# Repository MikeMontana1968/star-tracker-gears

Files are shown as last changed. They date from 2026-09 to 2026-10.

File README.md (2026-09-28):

# Sidereal star tracker

A standalone device that turns a camera at one revolution per **sidereal day**
(86164.0905 s) for wide-field astrophotography. It wakes at dusk, configures and
starts a GoPro HERO6 night lapse, tracks until dawn, stops the camera, and
rewinds ready for the next night.

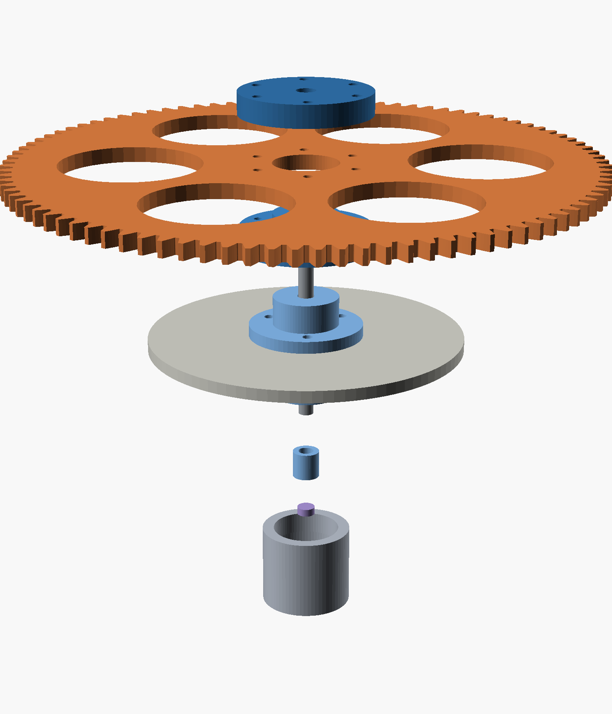
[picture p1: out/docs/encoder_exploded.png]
assembly


---

> **Picking this up again?** Read **[RESUME.md](RESUME.md)** first. The
> controller PCB (Rev C, for the 30-pin ESP32 in hand) is generated, clean
> in ERC and DRC, and ready to order.
>
> **Building it?** The illustrated assembly guide is
> [docs/assembly_guide/stjarnspar.html](docs/assembly_guide/stjarnspar.html):
> gearbox, board, smoke test, wiring, first power-up, use, and the schematics.
> Rebuild it with `python docs/assembly_guide/build.py` (needs Fritzing 1.0.8
> and KiCad 10). The Fritzing wiring project is
> [hardware/fritzing/star_tracker_wiring.fzz](hardware/fritzing/star_tracker_wiring.fzz),
> generated by `gen_fritzing.py` from the KiCad layout.

## Where this stands

| Area | State |
|---|---|
| Gearbox design | **Settled.** 2048:1, verified in CAD, every STL manifold |
| Printer calibration | **Measured.** Post/hole offset 0.50 mm; motor pinion bore pending one test print |
| Backlash | **Validated** on a test pair at 0.25 mm. One drag spot traced to the pinion — reprint with Z Seam = Random |
| Baseplate | **Ordered** from SendCutSend, 4.3 mm 6061 |
| Output shaft + encoder | **Designed**, needs the bearing gauge printed before the tower |
| Electronics | **PCB Rev C** ([hardware/PCB.md](hardware/PCB.md)) — 150 x 100 mm, all through-hole, every module socketed, generated from source; laid out for the 30-pin ESP32 after the pin check. ERC/DRC clean, not yet fabricated |
| Firmware | **Architecture settled** ([FIRMWARE.md](FIRMWARE.md)); nothing written beyond the timing core |
| Under the sky | Not yet |

**Next three things**, in order:

1. Print `_scratch/BEARINGGAUGE_pockets.stl`, set `$BrgFit`, then print the tower.
2. Print `pinion.stl` + the two bore variants next to `stage.stl`; keep the one
   that slides onto the NEMA17 shaft without force.
3. Build the polar wedge. **Before** the gearbox — see §2 below.

---

## The train

```
NEMA17 --15T--> [120T|15T] --> [120T|15T] --> [120T|24T] --> 96T --> camera
   module 1.0       8:1            8:1            8:1        4:1
                                                        module 2.0
```

**8 × 8 × 8 × 4 = 2048 : 1**

| | |
|---|---|
| microsteps / sidereal day | 13,107,200 (200 steps × 1/32 × 2048) |
| step interval | 6573.80 µs |
| step rate | 152.13 steps/s |
| motor speed | 1.426 rpm |
| output resolution | 0.099 arcsec/µstep |
| centre distances | 67.5 / 67.5 / 67.5 / 120.0 mm |
| gear stack | 226.5 × 279 mm envelope, 24.5 mm tall |
| baseplate | 121.5 × 174 × 4.3 mm, ~182 g |

---

## The two things that actually matter

Everything else in this project falls out of these.

### 1. Only the final pinion's radius sets short-exposure trailing

For any mesh, both gears contribute equally to output error per unit
eccentricity — the pinion's smaller radius exactly cancels its higher reduction.
But their *periods* differ, and trailing depends on how much the error moves
**during** an exposure:

```
excursion over exposure t  =  (e / r_pinion) × 2π t / 86164
```

Only `r_pinion` survives. That one equation drove the redesign from 4608:1 to
2048:1: a module-2 24-tooth final pinion (r = 24 mm) instead of module-1 15-tooth
(r = 7.5 mm) cuts a 0.1 mm eccentricity from ~60 arcsec to ~19 arcsec on every
300 s sub. Stages 1–3 divide by 2048, 256 and 32 — they can be as sloppy as the
printer likes.

### 2. Polar alignment dominates all of it

```
1° of misalignment  →  ~16 arcsec/min of drift
```

That swamps every mechanical error above. A sight tube down the RA axis getting
you to 0.25° is worth more than any amount of gear precision. **Build the wedge
first.**

Derivations, rejected alternatives and the design history are in
**[DESIGN_NOTES.md](DESIGN_NOTES.md)**.

---

## Layout

Square fold, 90° at each stage. Shaft centres in mm:

| Shaft | x | y | Carries |
|---|---|---|---|
| 0 motor | 0 | 0 | 15T module-1 pinion |
| 1 | 67.5 | 0 | 120T + 15T |
| 2 | 67.5 | 67.5 | 120T + 15T |
| 3 | 0 | 67.5 | 120T + **24T module-2** |
| 4 output | 0 | −52.5 | 96T module-2, 196 mm OD, on bearings |

**Constraints this layout imposes** — all three were found by drawing it to scale:

- **Nothing over Ø13 mm inline at shafts 0–3.** Tightest radial clearance is
  `67.5 − 61 − 2.5 = 4.0 mm`, shaft to neighbouring wheel tip. A 625ZZ (16 mm)
  gives −1.5 mm and collides; a Ø10 spacer leaves 1.5 mm. **Never fit a stock
  5 mm shaft collar at shafts 2 or 3.**
- **Shafts 0 and 1 must stay below 19 mm.** The output wheel sits over both. A
  stock NEMA17 shaft is 24 mm and fouls it — trim to ~10 mm above the plate.
- **No top plate on shafts 0 and 1**, same reason. Cantilever them; their errors
  divide by 2048 and 256, so it costs nothing.

**Every mesh needs its own Z band.** `pinion_tip + wheel_tip = a + 2m` always, so
a pinion collides with any adjacent wheel, mating or not. Four meshes, four
bands, irreducible. Band *height* can shrink (3 mm faces take the stack from
24.5 to 16 mm) but band *count* cannot.

---

## Baseplate

121.5 × 174 × **4.3 mm** 6061 aluminium, ~182 g (4.3 was the nearest stock to
the 4.0 designed). Cut, not printed — too big for the bed, and it wants
stiffness rather than strength.

Thickness is dimensionally free here: **all gear heights reference the plate's
top face**, so it lives below the datum. It only moves fastener lengths.

The outline is a hull of lobes at the five shaft centres, **not** a slab under
the whole gear footprint: the wheels overhang on purpose, so the plate only
carries the shafts and the motor. That is what takes it from ~740 g to 170 g.

The wedge/tripod interface is **4 × M5 on Ø50 centred on the output axis**, not
on the plate centroid. The camera moment gets reacted where it is generated, and
that short load path is why 4 mm is enough.

- `out/docs/baseplate_cut.dxf` — **send this**, 4 ARC + 4 LINE + 16 CIRCLE.
  State **mm** on upload; R12 DXF has no reliable units record
- `out/docs/baseplate_cut.svg` — same geometry as SVG, 17 closed contours
- `out/docs/baseplate_template.pdf` — 1:1 on US Letter, two scale bars
- `out/docs/baseplate_assembly_guide.pdf` — bench reference: component outlines,
  spacer heights, fastener sizes. **Not to scale**, by necessity — the gear
  footprint is 226 × 279 mm

`baseplate_geom.py` is the single source for all three, so they cannot drift.
Never export DXF from OpenSCAD — it emits 708 loose LINE segments and no
circles at all.

---

## Output shaft and AS5600 encoder

The output is the one shaft that rotates. The encoder magnet must sit on the axis
and turn with the wheel, and the camera load wants real bearings anyway.

Printed tower halves, hubs, washer, cap and bracket, plus a 5 mm ground shaft
**cut to 55 mm**, 2 × 625ZZ, a **diametric** 6 × 2.5 magnet and an AS5600
breakout. Verified: **magnet face to die = 2.0 mm**, inside the sensor's
0.5–3.0 mm window; bearing centres 30 mm apart.

Three design points worth not undoing:

- **The tower halves clamp the baseplate between them** (Rev B). Rev A's cone
  under the flange sat inside the plate. See PRINTING.md.

- **The wheel locates on a Ø22 register** on the lower hub and is clamped by six
  M3 — not centred by its own bore. A printed 5.2 bore on a 5 mm shaft is worth
  ~0.2 mm of eccentricity, which is exactly what §1 says to avoid.
- **The sensor bracket registers on the same tower boss that holds the lower
  bearing, and stops against the tower's clamp disc.** The AS5600 needs the
  magnet centred within ~0.25 mm and gapped at 2.0 mm; both come from printed
  features rather than from careful assembly.

Firmware aid: the AS5600's `AGC` and `MAGNITUDE` registers report "too far / too
close" as a number, so the air gap is measured, not guessed.

---

## Scheduled operation

Full architecture, cycle diagram, BOM and pin map: **[HARDWARE.md](HARDWARE.md)**.

- **ESP32, not a Pi.** Unattended robustness: a flat battery mid-write corrupts
  an SD card, LittleFS comes back. Also ~0.6 W cheaper, ≈7 Wh a night.
- **GoPro over WiFi, not BLE.** The documented GoPro BLE API starts at HERO9 —
  the earlier HERO5 Bluetooth failure was expected, not a Pi problem. HERO6 uses
  the `gpControl` HTTP API at 10.5.5.9, woken by a magic packet.
- **Captive web UI on the ESP32's own AP.** No app, no pairing. One radio means
  one mode at a time, which keeps the state machine simple.
- **~43 Wh per night, 69% of it the camera.** Three nights unaided needs 130 Wh;
  a 6 Ah pack plus a 20 W panel is lighter and never runs out.

**Two cycle rules that are not obvious:** always approach the start angle from
the forward direction (rewind reverses ~750 arcsec of backlash, which otherwise
gets taken up as drift during your first subs), and bias the counterweight so the
mesh stays loaded on one flank.

### Why there is no speed feedback loop

A stepper is synchronous, and the ESP32 crystal is ±20 ppm — over a 300 s exposure
that is 0.000025° at the output. There is nothing for a speed loop to correct. Use
StallGuard for *stall detection*, which is a real failure mode.

What must be exact is the step interval: 6573.80 µs is not an integer, and
rounding costs ~5 s/day of drift. `sidereal_drive.ino` carries the remainder in a
64-bit accumulator, so the rate is exact for **any** ratio — which is what freed
the design to choose gears for mechanical convenience.

---

## Printer calibration — measured, not guessed

These live at the top of `build.ps1`. They are the hardest-won numbers here.

| Constant | Value | How it was found |
|---|---|---|
| `$Bore` | 5.20 | gears run on 4.88 mm 20d nails |
| `$MotorBore` | 5.45 | NEMA17's ground 5.00 mm shaft needs a bigger bore than the nails |
| `$PostD` | 4.70 | fit gauge |
| `$BrgFit` | 0.50 | **provisional** — print the bearing gauge |

**A printed post must run ~0.50 mm under a printed hole's nominal diameter** for
a snug rotating fit on this printer. That is hole shrink plus post growth
combined, and it is on the high side of typical (0.30–0.40), which hints flow
runs a few percent hot.

Three gauges exist because these cannot be predicted, only measured:
`FITGAUGE` (posts), `BOREGAUGE` (holes), `BEARINGGAUGE` (625ZZ pockets).

---

## Repo layout

```
star_tracker_gears.scad     the model — single source for every part
make_baseplate_pdf.py       1:1 drilling template (reportlab)
build.ps1                   regenerates every artifact
firmware/sidereal_drive/    ESP32 sketch
PRINTING.md                 what to print, in what order, with what settings
DESIGN_NOTES.md             why the gearbox is what it is
HARDWARE.md                 electronics architecture, BOM
FIRMWARE.md                 firmware architecture, pin map, build order — START HERE for code
hardware/                   the controller PCB, generated from Python
  PCB.md                    board design notes, jumpers, assembly order
  design.py                 netlist + values + the ESP32/TMC pin maps
  place.py                  floorplan; layout.py packer; route.py maze router
  star_tracker_ctrl/        the generated KiCad project
out/                        generated — meshes gitignored
  docs/                     renders, laser SVG, baseplate SVG, template
  _scratch/                 calibration gauges, test jig, superseded exports
```

## Building

```powershell
.\build.ps1                     # everything
.\build.ps1 -Group gears        # the parts you print
.\build.ps1 -Group encoder      # output shaft assembly
.\build.ps1 -Group calibration  # the three gauges
.\build.ps1 -Group docs         # renders, SVGs, PDF
.\build.ps1 -List               # show targets without building
```

Needs OpenSCAD 2021.01+ and Python with `reportlab`. Every STL target is checked
for `Simple: yes` and the build fails if one is not.

---

## Traps worth remembering

Each of these cost real time and none of them announce themselves.

- **OpenSCAD: `children()` nested inside `union()` inside `difference()` inside
  `if()` does not resolve.** The section cut silently did nothing. Apply cuts at
  the call site instead.
- **OpenSCAD preview mis-renders `difference()` when children carry `color()`.**
  Geometry was correct all along; only the OpenCSG preview lied. Section images
  need `--render`, which then discards colour — hence the exploded view.
- **PowerShell 5.1 strips inner quotes** from native-exe arguments, so
  `part="spacers"` arrives as a bare variable. Backslash-escape them. And `2>&1`
  on a native command wraps stderr in ErrorRecords that abort under
  `$ErrorActionPreference = 'Stop'`.
- **A part can be un-printable in every orientation.** The bearing tower had a
  166 mm2 first layer one way up and an 8 mm 90° ledge the other. Splitting it
  fixed the printing. Check bed contact area, not just overhang angle.
- **Check a printable part against its neighbours, not just the bed.** Rev A's
  split added a cone for printability that sat inside the aluminium plate. It
  was found by drawing the assembly guide, not by the build. Rev B puts the
  plate between the halves, so each prints plate-face-down and only narrows
  going up.
- **Verify meshes, not file sizes.** Bounding-box checks caught a wheel that had
  changed only in float formatting, and a D-shaft cut that had sliced the pinion
  into five disconnected bodies (`Volumes: 5` instead of 2).
- **Binaries need `.gitattributes`.** Without it a fresh Windows clone rewrites
  LF to CRLF *inside* the PDF and PNGs and corrupts them.

## Order of work

1. Calibration gauges, then the test pair. Tune `backlash`.
2. **Build the polar wedge before the gearbox.**
3. Open-loop drive, 50 mm lens, one 5-minute sub. **Measure the trailing.**
4. Only then decide what to fix. Adding an encoder before you have data is
   solving an imaginary problem — the encoder in this design is for *scheduling*
   and stall detection, not for correcting tracking.

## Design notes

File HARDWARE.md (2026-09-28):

# Hardware — scheduled star tracker

Scope beyond the gearbox: a standalone device that wakes at dusk, configures and
starts a GoPro HERO6 night lapse, tracks at sidereal rate until dawn, stops the
camera, and rewinds ready for the next night.

---

## 1. Decisions, and why

### Controller: ESP32, not a Pi

| | ESP32 | Pi Zero W | Pi 4 |
|---|---|---|---|
| Idle power | ~0.3 W | ~0.9 W | ~3 W |
| Boot | instant | ~30 s | ~30 s |
| Survives a flat battery mid-write | yes | **SD corruption risk** | same risk |
| Step timing | hardware timers, no OS jitter | userspace, fine in practice | same |
| Web UI effort | moderate (ESPAsyncWebServer) | trivial (Flask) | trivial |
| RTC | needs DS3231 | needs DS3231 | needs DS3231 |

The deciding factor is not speed, it is **unattended robustness**. This device
sits outside for days and will eventually have its battery go flat mid-operation.
An ESP32 comes back up in a second with its LittleFS schedule intact; a Pi with a
half-written SD card may not come back at all. The extra 0.6 W also costs ~7 Wh a
night, which is real against a 43 Wh budget.

A Pi Zero 2 W with a **read-only root filesystem** is a legitimate alternative if
you would rather write Python — that closes the corruption gap. It does not close
the power or boot-time gap. A Pi 4 is the wrong shape for a battery device.

### Camera control: WiFi, not Bluetooth

Your earlier Pi-Zero/HERO5 Bluetooth failure was not a Pi problem — it was
expected. **The documented GoPro BLE API (OpenGoPro) starts at HERO9.** HERO5 and
HERO6 are controlled over WiFi through the `gpControl` HTTP API, which is well
documented by the community
([KonradIT/goprowifihack](https://github.com/KonradIT/goprowifihack/tree/master/HERO6)).

- Camera is the access point; controller joins it. Base URL `http://10.5.5.9/gp/gpControl`
- Wake from standby with a **Wake-on-LAN magic packet** to the camera's WiFi MAC,
  UDP port 9 (documented for HERO6)
- `GET /gp/gpControl/status` returns the full state as JSON
- `GET /gp/gpControl/setting/<id>/<value>` for exposure, interval, ISO limit
- `GET /gp/gpControl/command/shutter?p=1` / `p=0` start and stop
- `GET /gp/gpControl/command/system/sleep` standby

**Do not hardcode setting IDs from a blog post.** `GET /gp/gpControl` returns the
camera's own settings tree — dump it from your actual HERO6 and read the night
lapse mode and shutter IDs out of it. Firmware ships a `discover` command to do
exactly that.

**Caveat to verify on your camera:** `system/sleep` is standby, not off. The
camera keeps its WiFi radio listening so WoL can reach it, and that draws from
the internal battery. Budget for it, or cut the USB rail during the day and let
the internal battery hold standby — the load switch in the BOM lets firmware
choose. Measure it before trusting either.

### Phone interface: captive web UI, not an app

The ESP32 raises its own AP on a button press, serves a single page, and takes a
JSON schedule. No app to install, no pairing, works from any phone or laptop, and
sidesteps BLE entirely. **One radio means one mode at a time** — the controller
is either its own AP (configuring) or a station on the GoPro's AP (commanding the
camera). Never both. That constraint is what makes the state machine simple.

### Position: absolute encoder, so "home" needs no search

An **AS5600** on the output shaft reports absolute angle over I²C at power-up —
12-bit, 0.088° (5.3 arcmin). No homing sweep, no index hunt, and the same sensor
gives you skip detection during tracking.

This requires the output shaft to **rotate in bearings** rather than being a fixed
nail with the wheel turning on it, so the magnet can sit on the shaft end. That is
a change worth making regardless: the output carries the camera and deserves real
bearings.

Cheaper alternative: an opto-interrupter and a printed flag on the wheel rim,
~±0.06° repeatable, but it needs a homing sweep at power-up and gives no
continuous feedback. Listed as optional in the BOM.

---

## 2. Operating cycle

```
  IDLE (deep sleep, RTC alarm armed)
    |
    v  alarm at astronomical dusk - lead time
  ORIENT      read AS5600, slew to the start angle, approach FORWARD
    |
    v
  WAKE CAM    WoL magic packet, join GoPro AP, poll /status until ready
    |
    v
  CONFIGURE   set night lapse mode, shutter, ISO limit, interval
    |
    v
  RECORD      shutter?p=1, then DROP WIFI and start stepping
    |
    v  ...tracking at 6573.80 us/microstep...
    v  alarm at sunrise
  STOP CAM    rejoin AP, shutter?p=0, system/sleep, drop WiFi
    |
    v
  REWIND      slew back, overshoot, approach start FORWARD
    |
    v
  IDLE
```

Two rules that are not obvious:

**Always approach the start angle from the forward (tracking) direction.**
Backlash referred to the output is dominated by the final mesh:
`0.35 mm / 96 mm = 3.6 mrad ≈ 750 arcsec`. Rewinding reverses the gear train, so
if you stop on the reverse stroke that lost motion is taken up during your first
minutes of tracking — as drift. Overshoot and come forward.

**Keep the mesh loaded.** With a perfectly balanced camera the tracking torque
is near zero and the teeth can rattle across the backlash. Deliberately bias the
counterweight so the load always pulls the same way.

---

## 3. Power

Measured against a 12-hour night:

| Load | Power | Per night |
|---|---|---|
| GoPro HERO6, night lapse over USB-C | 2.5 W | 30.0 Wh |
| Stepper + TMC2209 tracking | 0.75 W | 9.0 Wh |
| ESP32 awake, radio off | 0.3 W | 3.6 Wh |
| RTC + encoder | 0.05 W | 0.6 Wh |
| GPS, powered only for the nightly fix | 0.22 W | **<0.1 Wh** |
| Rewind slew | 3 W for ~4 min | 0.2 Wh |
| **Total** | | **~43 Wh** |

**The camera is 69% of the budget.** Any power optimisation that is not about the
GoPro is noise.

Your 3-day schedule therefore needs ~130 Wh plus daytime standby. That is a
12 V 12 Ah LiFePO4 — about 1.8 kg. **A 12 V 6 Ah pack plus a 20 W solar panel is
lighter, cheaper, and makes the device indefinitely autonomous** — 43 Wh is about
four hours of decent sun. For a device whose entire job is to sit outside all day
doing nothing, solar is the obvious fit.

---

## 4. Bill of materials

Prices are rough and vary; treat as sizing, not quotes.

### Control board (see [hardware/PCB.md](hardware/PCB.md))

Everything in this table lives on the `star_tracker_ctrl` PCB. It is
**entirely through-hole**, and every module sits in a socket rather than being
soldered down.

| Qty | Ref | Item | ~USD | Notes |
|---|---|---|---|---|
| 1 | — | PCB, 127 x 76.2 mm, 2-layer, 1.6 mm | 12 | qty 5 from a cheap fab |
| 1 | — | ideaspark ESP32 + 0.96" OLED, 30-pin, CH340 | 10 | **have**; rows 27.94 mm, pin check done (no PSRAM, OLED on 21/22) |
| 2 | J20/J21 | 1x15 female header, 2.54 mm | 2 | the ESP32 socket |
| 1 | — | TMC2209 StepStick, UART mode | 7 | BTT / Fysetc / Watterott |
| 1 | J30/J31 | 1x08 female header, 2.54 mm | 1 | the driver socket |
| 1 | — | DS3231 RTC module (ZS-042) + CR2032 | 4 | ±2 ppm. **Not** DS1307 |
| 1 | J6 | 1x06 female header | 1 | RTC socket |
| 1 | — | AS5600 encoder module | 4 | remote, on the encoder bracket |
| 1 | — | Diametric magnet 6 x 2.5 mm | 2 | must be **diametric** |
| 1 | — | **GY-NEO6MV2 GPS module** (NEO-6M) + antenna | 8 | time, date and position. **PPS is not on its 4-pin header** — solder a lead at the PPS LED |

### Power stage (on the PCB)

12 V in, protected, to a 5 V 3 A switching rail with a firmware-switched
camera output.

| Qty | Ref | Item | ~USD | Notes |
|---|---|---|---|---|
| 1 | U2 | **LM2596T-5.0**, TO-220-5 | 2 | 150 kHz, 3 A, fixed 5 V |
| 1 | — | TO-220 clip-on heatsink | 1 | **fit it** — see PCB.md §5 |
| 1 | L1 | 33 µH radial power inductor, >=3 A | 2 | 12 mm body, 5 mm pitch |
| 1 | D3 | 1N5822, 3 A 40 V Schottky, DO-201AD | 0.5 | catch diode |
| 1 | C3 | 470 µF 25 V low-ESR | 1 | buck input |
| 1 | C5 | 220 µF 25 V low-ESR | 1 | buck output |
| 1 | C1 | 470 µF 25 V | 1 | 12 V bulk |
| 1 | C11 | 100 µF 25 V low-ESR | 1 | **VMOT, at the driver socket** |
| 2 | Q1 Q2 | IRF4905 P-MOSFET, TO-220 | 2 | reverse-polarity + camera switch |
| 1 | Q3 | 2N3904 NPN, TO-92 | 0.2 | gate driver for Q2 |
| 1 | Q4 | 2N3906 PNP, TO-92 | 0.2 | GPS 5 V high-side switch |
| 1 | Q5 | 2N3904 NPN, TO-92 | 0.2 | drives Q4 from GPIO 17 (GPS_EN) |
| 1 | D1 | 1N4744A 15 V zener, DO-41 | 0.2 | Q1 gate clamp |
| 1 | D2 | P6KE20CA TVS, DO-15 | 0.5 | input transient clamp; bidirectional |
| 1 | F1 | 5x20 mm fuse holder + 3 A fuse | 2 | PCB clips |
| 3 | LED1-3 | 3 mm LED (grn, grn, **red**) | 0.5 | 5 V / camera / status. LED3 runs off a 3.3 V GPIO, so red + 330 R — blue would barely light |
| 1 | SW1 | 6 mm tactile switch | 0.3 | config + wake |

### Connectors and passives (on the PCB)

| Qty | Ref | Item | ~USD | Notes |
|---|---|---|---|---|
| 2 | J1 J3 | 2-pos screw terminal, 5 mm | 1 | 12 V in, camera 5 V out |
| 1 | J4 | 4-pos screw terminal, 5 mm | 1 | motor |
| 1 | J2 | USB-A receptacle, THT horizontal | 1.5 | camera; D+/D- shorted |
| 1 | — | 1x40 male header strip, 2.54 mm | 1 | cut for J5/J7-J11/JP3-JP5 |
| 5 | — | 2.54 mm jumper shunts | 0.5 | MS1, MS2, PDN_ALT |
| 9 | C2.. | 100 nF ceramic, 2.5 mm pitch | 1 | decoupling |
| 2 | C7 C9 | 100 µF 16 V / 10 V | 1 | camera rail, 3V3 |
| 19 | R1.. | 1/4 W resistors, see PCB.md | 1.5 | 2x 1% for the battery divider |
| 4 | H1-H4 | M3 standoff + screw | 2 | |

### Motion

| Qty | Item | ~USD | Notes |
|---|---|---|---|
| 1 | NEMA 17 pancake, ~13 N·cm, 0.7 A | 14 | 250× torque margin; run at 300–400 mA |
| 2 | 625ZZ bearing 5 × 16 × 5 | 3 | output shaft only |
| 1 | 5 mm ground shaft | 4 | output shaft, cut to **55 mm**; carries the encoder magnet |
| 1 | 20d bright common nails, small box | 6 | 4.88 mm, shafts 1–4 |
| 1 | M3 hardware assortment | 8 | grub screws, caps, washers |

### Power

| Qty | Item | ~USD | Notes |
|---|---|---|---|
| 1 | 12 V 6 Ah LiFePO4 with BMS | 45 | ~1.8 nights unaided |
| 1 | 5 V 3 A buck converter | 6 | camera rail; **not** a linear regulator |
| 1 | 20 W solar panel + PWM/MPPT controller | 45 | *recommended* — makes it indefinite |
| 1 | Inline fuse holder + 3 A fuse | 3 | |
| 1 | XT60 or 5.5/2.1 mm barrel pair | 4 | |

### Camera

| Qty | Item | ~USD | Notes |
|---|---|---|---|
| 1 | GoPro HERO6 | — | have |
| 1 | Short right-angle USB-C cable | 8 | |
| 1 | 6-wire capsule slip ring | 12 | *optional* — a slack loop covers 180° |
| 1 | GoPro frame + ¼"-20 adapter | 8 | |
| 1 | Counterweight hardware | 6 | bias it to keep the mesh loaded |

### Enclosure

| Qty | Item | ~USD | Notes |
|---|---|---|---|
| 1 | IP54 project box | 15 | |
| 3 | Cable glands | 4 | |

The transistor switch on the GPS 5 V feed is there for a reason: left
powered the NEO-6M draws 30-45 mA around the clock, roughly 5 Wh a day doing
nothing at all. Switched on only for the nightly fix, it costs under 0.1 Wh.

**Roughly $205 without solar, $255 with** (the PCB and its discrete
power stage replace the perfboard, the buck module and the load-switch module).

---

## 5. Pin map

> **Superseded — see [FIRMWARE.md §4](FIRMWARE.md#4-pin-map--as-built).**
> The table below predates the OLED devkit and is missing the DS3231 interrupt
> line, without which the RTC alarm cannot wake the ESP32 from deep sleep.
> FIRMWARE.md §4 is the authoritative map. Kept here for the wiring rules only.

| ESP32 | To | Note |
|---|---|---|
| GPIO 25 | TMC2209 STEP | LEDC for slew, timer ISR for tracking |
| GPIO 26 | TMC2209 DIR | |
| GPIO 27 | TMC2209 EN | active low |
| GPIO 17 | TMC2209 PDN_UART | via 1 kΩ for single-wire |
| GPIO 16 | TMC2209 UART RX | |
| GPIO 21 / 22 | I²C SDA / SCL | DS3231 @0x68, AS5600 @0x36 — no conflict |
| GPIO 4 | config button | to GND, internal pull-up |
| GPIO 34 | battery sense | ADC via divider; input-only pin |
| GPIO 35 | opto home flag | *optional*; input-only pin |
| GPIO 32 | camera 5 V load switch | |
| GPIO 2 | status LED | onboard |

Avoid GPIO 6–11 (flash) and 0/12/15 (strapping).

**Wiring rules that kill drivers if ignored:** 100 µF low-ESR across VMOT right
at the TMC2209; common ground between ESP32 and driver; never unplug the motor
with power applied; TMC2209 VDD from **3.3 V**, not 5 V.

---

## 6. Open items

- [ ] Dump `/gp/gpControl` from the actual HERO6 and pin down night-lapse mode
      and shutter setting IDs
- [ ] Measure HERO6 standby draw with WiFi listening — decides whether the day
      rail stays on
- [ ] Confirm WoL wakes your camera reliably from cold-ish standby
- [ ] Redesign the output shaft: two 625ZZ bearings, rotating shaft, encoder
      magnet at the lower end, camera platform above
- [ ] Confirm the HERO6 keeps its AP rejoinable after the ESP32 disconnects
      mid-record — if not, the dawn stop has to become a load-switch cut, which
      loses the last file
- [ ] Cable routing for 180° of sweep — slack loop vs slip ring
- [ ] Decide battery vs battery+solar

Firmware architecture, state machine, schedule format and build order:
**[FIRMWARE.md](FIRMWARE.md)**.

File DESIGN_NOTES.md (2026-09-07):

# Star Tracker Gear Drive — Design Notes

Working notes for a printed gear train that rotates a camera at one revolution
per sidereal day, driven by a stepper on an ESP32.

`README.md` is the build sheet — what to print and what to set.
This file is the *reasoning*: why these numbers, and what was rejected.

Status: design settled at **2048:1** with a module-2 final stage. Accuracy
targets are deliberately loose; first light intended on a 50 mm lens.

The 4608:1 module-1 train described in §2 was the first design. It was replaced
after §3 showed the final *pinion* radius, not the wheel, sets short-exposure
trailing — see §3a. The history is kept because the reasoning still applies.

---

## 1. Tools surveyed

Before writing a custom generator, the existing options:

**Browser, no install**

| Tool | Notes |
|---|---|
| [STLGears](https://www.stlgears.com/generators/3dprint) | Fast one-offs. Spur/helical/bevel/rack, direct STL, no account. |
| [Gear Generator Pro](https://geargenerator.pro/) | Widest coverage — spur, helical, bevel, worm, rack, sprockets. Live 3D preview. |
| [EasyGear Maker](https://easygear.ddns.net/en/) | Best of the web tools if the mesh has to *work*: true involute, exposes profile shift and backlash, exports STEP. |
| [The Engineer Online](https://www.theengineer.online/) | DXF/SVG/STEP/STL including internal gears. Good when you want the 2D profile. |
| [geargenerator.com](https://geargenerator.com/) | Animates a train — useful as a ratio calculator, weak on export. |

**Parametric**

| Tool | Notes |
|---|---|
| [chrisspen/gears](https://github.com/chrisspen/gears) | OpenSCAD port of Dr. Kirsch's `getriebe.scad`. Spur/ring/bevel/worm/rack **plus prebuilt assemblies** with correct centre distances. The serious choice. |
| [playfultechnology/openscad-gears](https://github.com/playfultechnology/openscad-gears) | Lighter-weight alternative. |
| Fusion 360 Spur Gear add-in | Utilities → Add-Ins → Scripts. Gives real B-rep, so you can cut hubs and keyways into it. |
| FreeCAD FCGear workbench | Via Addon Manager. Full involute/bevel/worm/cycloid, parametric. |

**Why a custom file anyway:** this train needs *compound* gears (wheel + next
pinion on one hub) with mount features, printed 3× identically. Writing ~200
lines of self-contained OpenSCAD was less work than fighting a library's
assembly conventions, and it version-controls as text.

---

## 2. Ratio selection

Sidereal day = **86164.0905 s**.

Working backward from motor speed:

| Motor speed | Reduction needed |
|---|---|
| 1 RPM | 1436 : 1 |
| 3 RPM | 4308 : 1 |
| 10 RPM | 14361 : 1 |

Below ~1 RPM the motor's own 50-cycle/rev torque ripple starts to show.
Above ~5 RPM you buy extra gear stages you don't need. **~3 RPM is the sweet spot.**

Chose **4608 : 1 = 8 × 8 × 8 × 9** because it factors into one repeated part:

```
NEMA17 --15T--> [120T|15T] --> [120T|15T] --> [120T|15T] --> 135T --> camera
         8:1          8:1            8:1            9:1
```

Five printed parts, two distinct designs. At 200 steps/rev, 1/16 microstepping:

| | |
|---|---|
| microsteps / sidereal day | 14,745,600 |
| step interval | 5843.377 µs |
| step rate | 171.13 steps/s |
| motor speed | 3.209 RPM |
| output resolution | 0.088 arcsec/µstep |

Module 1.0, 20° PA. Centre distances **67.5 / 67.5 / 67.5 / 75.0 mm**.
ODs: 15T = 17 mm, 120T = 122 mm, 135T = 137 mm. All fit an Ender 3 bed.

**Don't chase "nice" numbers.** The software accumulator (§4) makes any ratio
exact, so gears get chosen for mechanical convenience, not numerology.

### Rejected: single-stage worm

60:1 or 90:1 in one stage is tempting, but it puts the motor at ~0.04 RPM —
deep into torque-ripple territory. Worms belong in the *final* stage, not as
the whole reduction. See §6.

---

## 3a. The correction that reshaped the design

The table in §3 tracks the **wheels**. It misses the pinions, and the pinions
are what matter.

For any mesh both gears contribute equally to output error per unit
eccentricity — the pinion's smaller radius exactly cancels its higher
reduction. But the periods differ, and trailing depends on how far the error
moves *during* an exposure:

```
excursion over exposure t  =  (e / r_pinion) x 2*pi*t / 86164
```

Only the final pinion's pitch radius appears. With the original 15T module-1
pinion (r = 7.5 mm) a 0.1 mm eccentricity gives ~60 arcsec over a 300 s sub —
nine times worse than the 135T wheel the §3 table fingered.

**Final design: 24T pinion / 96T wheel at module 2.0, 4:1.** r_pinion goes
7.5 -> 24 mm, and that 60 arcsec becomes ~19. Total ratio 8x8x8x4 = **2048:1**,
`USTEPS_PER_REV = 13,107,200` at 1/32 microstepping.

The same change makes the wheel laser-cuttable if you ever want it in metal:
module-1 tooth tips are 0.69 mm, module-2 tips are 1.43 mm.

A single defective tooth is a smaller problem than it first appears. Trailing
comes from error *changing* during an exposure, so a sub taken wholly inside one
tooth's engagement sees a constant offset that stacking removes. Only subs
straddling the bad tooth's entry or exit are damaged — about 6% of them.

## 3. Error budget — the useful part

Each shaft's eccentricity is divided by the reduction **downstream** of it:

| Shaft | rev/day | period | 0.1 mm eccentricity → output error |
|---|---|---|---|
| 0 (motor pinion) | 4608 | 18.7 s | ~0.001″ |
| 1 | 576 | 2.5 min | ~0.6″ |
| 2 | 72 | 20 min | ~4.6″ |
| 3 | 9 | 2.7 h | ~37″ |
| 4 (output, 135T) | 1 | 23.9 h | ~305″ |

**Only the last stage matters.** Stages 1–3 can be as sloppy as the printer
likes. This is why the output wheel is the biggest one — angular error scales
as 1/R, so print it as large as the bed allows.

The 305″ on the output sounds fatal but its *period* is a whole day, so within
a 300 s exposure you only see about **6.7 arcsec** of it:

```
excursion ≈ A × 2π × t_exposure / 86164
          = 305 × 2π × 300 / 86164 ≈ 6.7″
```

- 50 mm lens on APS-C ≈ 16 arcsec/px → invisible.
- 200 mm lens ≈ 4 arcsec/px → ~1.7 px of trailing, borderline.

**Start on a 50 mm.**

### What actually ruins subs

**Polar alignment.** Misalignment θ drifts at θ·ω where ω = 7.292e-5 rad/s:

```
1° = 3600″ → 3600 × 7.292e-5 = 0.263 ″/s = ~16 arcsec/min
```

That swamps every mechanical error above. Getting to 0.25° with a sight tube
down the RA axis buys more than any amount of gear precision. **Do this first.**

---

## 4. Why there is no speed feedback loop

A stepper is *synchronous* — it advances exactly one microstep per pulse. The
ESP32 crystal (±20 ppm) is the timebase, and over a 300 s exposure that is
±6 ms ≈ 0.000025° at the output. Four orders of magnitude better than the
mechanics. **There is nothing for a speed loop to correct.**

What feedback *is* worth having: **stall / skip detection.** A TMC2209 gives it
free over UART via StallGuard. An AS5600 on an intermediate shaft also works
(12-bit = 0.088°, ÷9 through the final stage = ~35″ at the output — coarse for
correction, fine for "is it still turning?").

### The one thing that must be exact

The step interval 5843.377… µs is **not** an integer. Rounding to 5843 µs loses
0.377 µs × 171 steps/s = 65 µs/s = **5.6 s/day ≈ 23 arcsec of drift.** Visible.

So never round — carry the remainder, Bresenham style:

```c
const uint64_t SIDEREAL_US    = 86164090500ULL;      // µs
const uint64_t USTEPS_PER_REV = 200*16*4608;         // 14,745,600

acc += SIDEREAL_US;
uint64_t dt = acc / USTEPS_PER_REV;   // alternates 5843 / 5844
acc -= dt * USTEPS_PER_REV;           // remainder carries forward
next_us += dt;
```

Long-term rate is exact for **any** gear ratio. Change `USTEPS_PER_REV` and
nothing else. Use `esp_timer_get_time()` (int64 µs, monotonic, never wraps),
not `micros()`.

Run the motor at **low current (300–400 mA)** — it needs almost no torque
through 4608:1, and low current means less vibration and heat.

---

## 5. The generator

`star_tracker_gears.scad`, self-contained, no libraries.

**Involute construction.** Flank angle at radius R:

```
θ(R) = ψ_pitch + inv(α) − inv(acos(r_base/R))
```

with `inv(a) = tan(a) − a`, and `ψ_pitch = 90/z` degrees minus the backlash
allowance. Below the base circle the flank extends radially (conservative —
a real trochoid root is more generous). Root fillets come from a morphological
closing, `offset(r=-f) offset(r=+f)`, which rounds concave corners only.

**Helix done right.** Twist is computed *per gear* from a shared helix angle β:

```
twist_deg = h · tan(β) / r_pitch · 180/π
```

Applying the same twist *degrees* to a 15T and a 120T — which most generators
do — produces gears that will not mesh, because `r` differs. Cutting in the
transverse plane also keeps centre distance exactly `m(z₁+z₂)/2`.

**Mount features** (§ README) — `mount_type` / `out_mount`:
`round`, `dshaft`, `hex`, `bearing`, `thread`. Plus an M3 grub screw and a
parametric bolt circle. Lightening holes compute their inner radius from
whatever the bolt circle and bearing boss need.

### Two constraints found the hard way

1. **A bearing pocket does not fit the compound `stage` gear.** A 625ZZ is
   16 mm across; the 15T pinion's root circle is 12.5 mm. The pocket eats the
   pinion. Bearings go in the **frame**, plain shaft through the gear — which
   is what a real gearbox does. Hence `mount_type` and `out_mount` are separate.

2. **A D-hole is the circle *minus* the flat side**, not the circle plus a slot.
   The first attempt cut an oversized slot outward, sliced teeth off, and
   produced 5 disconnected bodies. Caught by checking `Volumes:` in the render
   output — `2` means one solid, anything more means the part fell apart.

### Verification

All parts render manifold (`Simple: yes`, `Volumes: 2`) in every `mount_type`.
Console echo confirms `ratio = 4608 : 1` and
`centre distances = [67.5, 67.5, 67.5, 75]`.

```powershell
& "C:\Program Files\OpenSCAD\openscad.exe" -o out\stage.stl -D 'part="stage"' star_tracker_gears.scad
```

**Using the GUI:** F5 = fast preview, F6 = full render (needed before STL
export), F7 = export. `$t` is 0 under F5, so nothing moves — for motion use
**View → Animate**, then FPS 10 / Steps 100. Scrubbing the `Time` field by hand
is usually more informative than watching it spin.

The 135T wheel takes ~2 min to F6. That is `offset()` doing fillets on 135
teeth, not a hang. Set `fillet = 0` and `flank_pts = 8` while experimenting.

---

## 6. Upgrade path — same firmware

Replace stages 3 and 4 with a worm:

```
NEMA17 --15T--> [120T|15T] --> [120T|15T] --> 1-start worm --> 72T wheel
         8:1          8:1                            72:1
```

8 × 8 × 72 = 4608 : 1, so `USTEPS_PER_REV` changes to 200 × 32 × 4608.
A worm final stage has no backlash reversal, is nearly self-locking, and a
*bought brass* worm wheel removes the single largest error source in the design
(§3). This is what a real EQ mount does.

---

## 7. The lazier alternative

A **barn-door tracker** — hinged plate pushed by a threaded rod on a long lever
— gets ~1000:1 mechanical advantage for free, makes printed-part precision
almost irrelevant, and is a weekend build. It only tracks for about an hour
before tangent error accumulates, and needs an isosceles or curved-rod
correction beyond that.

If "get a feel" is genuinely the goal, that is the better *first* project.
The gearbox is the better second one.

---

## 8. Order of work

1. Print `test_pair`. Tune `backlash` until it turns freely with barely
   perceptible slop. Everything downstream depends on this one number.
2. Build the polar alignment **before** the gearbox.
3. Open-loop drive, 50 mm lens, one 5-minute sub. **Measure the trailing.**
4. Only then decide what to fix. Adding an encoder before you have data is
   solving an imaginary problem.

## Print settings (Ender 3 / V3 SE)

- Module 1.0 at 0.4 mm nozzle → ~1.57 mm tooth thickness at the pitch line,
  about 4 extrusion widths. Fine at these loads. **Do not go below module 1.0.**
- `backlash = 0.25` mm total per mesh is the PLA starting point. Binds → 0.35.
  Rattles → 0.15.
- 0.12–0.16 mm layers, **4 perimeters**, ≥40% infill. Perimeters carry the
  teeth, so more perimeters beats more infill.
- Flat on the bed, no supports. Lightening holes are already in the wheels.
- **PLA, not PETG** — PETG creeps under sustained load.
- Shafts: 5 mm. M5 bolts work. 625ZZ (5×16×5) on the last two shafts, which
  are the ones that matter.

---

## 9. Assembly constraints found during layout

Three of these only surfaced when the layout was drawn to scale. All are now
enforced in `star_tracker_gears.scad` or documented on the drilling template.

**Every mesh needs its own Z band — the stack cannot be flattened.** For any
mesh, `pinion_tip + wheel_tip = a + 2m`: the tip circles always overlap by two
modules. So a pinion collides with *any* wheel on an adjacent shaft, mating or
not. Four meshes, four bands, irreducible. What can shrink is band height —
3 mm faces and a 1 mm gap take the stack from 24.5 mm to 16 mm.

**The assembly is a pancake, not a staircase.** Drawn folded and at true scale
it is 226 mm across and 24.5 mm tall. The three 122 mm wheels overlap almost
completely in plan; only the Z staircase separates them.

**Spacer OD is the tightest fit in the box.** A spacer on shaft 2 shares a Z
band with shaft 1's wheel: `67.5 - 61 - 5.0 = 1.5 mm` at Ø10, and zero at Ø13.
Never fit a stock 5 mm shaft collar (12-16 mm OD) at shafts 2 or 3.

**The output wheel sits over shafts 0 and 1.** They must stay below 19 mm, and
cannot reach a top plate. Harmless — their errors divide by 2048 and 256.

**Consecutive wheels were originally coplanar** with zero axial gap, and the
lowest gear sat flat on the baseplate. Both fixed with `z_gap` and `sp_clr`.
`fw_pinion` is 2 mm wider than `fw_wheel` precisely so the axial gap can exist
while the pinion still covers the full wheel face.

## 10. Printer calibration

Measured, not assumed: **a printed post must run ~0.50 mm under a printed
hole's nominal diameter** for a snug rotating fit on this machine — hole shrink
plus post growth combined. High side of typical (0.30-0.40), which hints flow
runs a few percent hot.

Consequences: gears carry a 5.2 bore and run on **20d common nails (4.88 mm)**,
which fit the as-printed hole better than true 5.00 mm ground stock would. The
motor pinion is the exception — it goes on the NEMA17's ground 5.00 mm shaft
and needs ~5.45, with the D-flat scaled to match at `2.0 + (bore - 5.0)/2`.

These constants live at the top of `build.ps1`.

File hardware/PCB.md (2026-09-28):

# star_tracker_ctrl — controller PCB, Rev C

A 150 × 100 mm (5.9 × 3.9 in) two-layer carrier board for the sidereal
tracker: 12 V in, protected and fused, a 5 V 3 A switching rail, a
firmware-switched camera output, and sockets for the ESP32, the TMC2209 and
the DS3231.

Architecture, state machine and pin map: **[../FIRMWARE.md](../FIRMWARE.md)**.
Project-level BOM: **[../HARDWARE.md §4](../HARDWARE.md)**.

---

## 0. Read this before you order

Rev C is drawn for the module in hand, the **30-pin ideaspark ESP32 + 0.96"
OLED** (silkscreen `ESP32 OLED-0.96 V3.0`, DOIT DevKit V1 layout). These were
measured or checked on that module:

- [x] **Row spacing 27.94 mm (1.1 in), pitch 2.54 mm, 15 pins per side** —
      measured. [`design.py`](design.py) `ESP32_ROW_SPACING` / `ESP32_PINS_PER_SIDE`.
- [x] **Pin order** read off the module's silkscreen; the map is FIRMWARE.md §4.
- [x] **Pin check, 2026-09-27:** the OLED answers at `0x3C` on GPIO 21/22 (it
      shares the sensor bus, GPIO 4 stays free for WAKE), and there is **no
      PSRAM** — WROOM-class, GPIO 16/17 free.
- [ ] Using a different ESP32 board? Redo all three: measure the rows, read
      the pin order, run `firmware/pincheck`. A Heltec-style board with the
      OLED on GPIO 4/15 needs a different map.
- [ ] Check the DS3231 module's pin order is `32K SQW SCL SDA VCC GND`
      (ZS-042). Other orders exist; the socket is labelled.
- [ ] Look at your GPS module for a **PPS pad**. The common GY-NEO6MV2 brings
      out only `VCC RX TX GND` and drives an on-board PPS LED instead, so
      you will be soldering a flying lead. See §6.

Everything is through-hole, and every module is socketed. There are no SMD
parts and no DIP ICs — the only IC is the LM2596 in a TO-220.

---

## 1. What is on it

| Block | Parts | Notes |
|---|---|---|
| Input protection | F1, Q1, D1, D2, C1 | 3 A fuse, P-FET reverse polarity, TVS |
| 5 V 3 A buck | U2, L1, D3, C3, C5 | LM2596T-5.0, 150 kHz |
| Camera switch | Q2, Q3, R3–R5, J2, J3 | high-side P-FET, USB-A + screw terminal |
| ESP32 socket | J20, J21 | 2 × 1×15, 27.94 mm apart (30-pin module) |
| TMC2209 socket | J30, J31 | 2 × 1×8, 15.24 mm apart (StepStick standard) |
| Motor | J4 | 4-pos screw terminal |
| RTC | J6 | DS3231 module socket |
| Sensors | J7, J8, J10 | AS5600 (remote), opto home, I²C expansion |
| GPS | J9, Q4, Q5 | GY-NEO6MV2 on a switched 5 V feed, plus PPS |
| v2 | J11 | spare IO: GPIO 39, 35 (input-only) |
| Jumpers | JP3, JP4, JP5, J5 | PDN alt, MS1, MS2, DIAG |

---

## 2. Power input

```
  J1 +12V ── F1 3A ──┬── Q1 IRF4905 ──┬── +12V rail
                     │   (D→in, S→out)│
                    GND        R1 10k ┴ GND,  D1 15V zener G–S clamp
                                      │
                               D2 P6KE20CA ── GND
                               C1 470µF ──── GND
```

**Q1's orientation is the part people get wrong.** For reverse-polarity
protection with a P-channel MOSFET, the **drain** goes to the supply and the
**source** to the load — not the other way round. The body diode runs
drain→source, so wired this way it is forward-biased in normal use (the
channel carries the current anyway, at ~20 mΩ) and **reverse-biased when the
supply is backwards**, which is the whole point. Wire it source-to-supply and
the body diode happily passes −12 V straight into the board.

D1 clamps V<sub>GS</sub> if a transient gets past the TVS. D2 is
**bidirectional** (P6KE20CA, not the unidirectional …A) so there is no
polarity to get wrong at assembly.

## 3. 5 V 3 A buck — LM2596T-5.0

Pin order confirmed against TI SNVS124G Table 6-1:
**1 = V<sub>IN</sub>, 2 = Output, 3 = GND, 4 = Feedback, 5 = ON/OFF.**

| | |
|---|---|
| Topology | fixed 5 V, 150 kHz, 3 A |
| Input cap | C3 470 µF 25 V **low-ESR** |
| Inductor | L1 33 µH, ≥3 A, 12 mm radial |
| Catch diode | D3 1N5822, 3 A 40 V Schottky, cathode on the SW node |
| Output cap | C5 220 µF 25 V **low-ESR** |
| ON/OFF | tied to GND = always on (open is also on) |
| Feedback | straight to the +5 V rail — this is the fixed-output part |

**Low-ESR is not optional** on C3 and C5. A general-purpose electrolytic will
work at room temperature and then make the loop unstable on a cold night.

### Fit the heatsink

At 3 A out the LM2596 dissipates about 1.7 W. A bare vertical TO-220 is
roughly 60 °C/W to still air, so that is a 100 °C rise — too hot. The real
load is much lower (the camera is ~0.5 A, ~1.5 A while it charges its own
battery, plus ~0.15 A for the ESP32), which is 0.4–0.6 W and fine bare. **Fit
a clip-on heatsink anyway** — it costs a dollar and the failure mode is a
thermal shutdown at 2 a.m.

If you would rather have 94 % and no inductor, a Traco **TSR 3-2450** (SIP-3,
3 A, 6.5–36 V in) is a drop-in *concept* replacement, but it needs a footprint
this project does not ship — its pin pitch is not verified here. The Recom
R-78B5.0-2.0 has a stock KiCad footprint but is only 2 A, which is under spec.

## 4. Camera 5 V switch

```
  +5V ──┬── R3 10k ──┬── Q2 gate       GPIO32 ── R4 10k ── Q3 base
        │            │                                  R5 100k ── GND
        └── Q2 source│
                     └── Q3 collector ── (Q3 emitter → GND)
  Q2 drain ── +5V_CAM ── C7 100µF ── J2 USB-A / J3 screw terminal
```

GPIO high → Q3 on → gate pulled to ground → V<sub>GS</sub> = −5 V → Q2 on.
R3 holds the gate at the source so the camera is **off by default**, including
while the ESP32 is unpowered or its GPIO is floating; R5 does the same for the
base. IRF4905 at V<sub>GS</sub> = −5 V is roughly 30 mΩ, so ~0.1 V and 0.15 W
at 1.5 A.

J2's D+ and D− are shorted together — the "dedicated charging port"
convention, which is what tells a GoPro it may draw full current.

## 5. GPS

```
       GPIO17 ──R18 10k──┬── Q5 base          +5V ──┬── R16 10k ──┬── Q4 base
                     R19 100k                       │             │
                         │                          └── Q4 emitter│
                        GND     Q5 collector ──R17 1k─────────────┘
                                Q5 emitter ── GND
                                Q4 collector ── GPS_VCC ── C17 ── J9.2
```

GPIO high turns Q5 on, which pulls Q4's base down through R17 and switches
5 V onto the module. R16 holds Q4 off by default and R19 does the same for
Q5, so **the GPS is off while GPIO 17 floats at boot**. Q4 is a 2N3906: at
45 mA it drops about 0.2 V, and the module's own LDO makes 3.3 V from what
is left. Its TX output is 3.3 V logic, safe straight into the ESP32.

**Why switch it at all:** the 3.3 V and 5 V rails both stay up through deep
sleep, so an unswitched GPS would pull 30–45 mA around the clock — roughly
5 Wh a day, for a part that has a job for about ninety seconds each evening.

### J9 pinout

| Pin | Signal | Note |
|---|---|---|
| 1 | **PPS** | flying lead — see below |
| 2 | VCC | switched 5 V |
| 3 | RXD | net `ESP_TX_GPS_RX`: module RX ← ESP32 TX (GPIO 5) |
| 4 | TXD | net `GPS_TX_ESP_RX`: module TX → ESP32 RX (GPIO 18) |
| 5 | GND | |

Pins 2–5 are deliberately in the module's own `VCC RX TX GND` order, so its
4-wire cable plugs straight in. **Pin 1 is separate because the GY-NEO6MV2
does not break PPS out** — the NEO-6M's TIMEPULSE drives the on-board PPS LED,
so tap it there. Check your board first; some revisions do have a PPS pad.

PPS is worth wiring, but keep its value in proportion: it sets the RTC to
sub-second accuracy and *measures* your crystal's real ppm error. It does not
meaningfully improve tracking — 20 ppm over a 12 h night is 3.6 arcsec at the
output, and polar alignment beats that by a thousand.

## 6. Module orientation — read this before fitting anything

**Every module on this board sits in a socket.** The ESP32 (J20/J21), the
TMC2209 (J30/J31) and the DS3231 (J6) are all female headers — nothing is
soldered down, and any of them can be pulled and replaced.

That makes orientation the thing that bites, because a socket will happily
accept a module fitted the wrong way round.

### The rule

The ESP32 module viewed from the top with its USB at the bottom has the left
column (`EN … VIN`) down the left edge and the right column (`IO23 … 3V3`)
down the right. Laid on its side there are exactly **two** legal placements:

| Rotation | Left column | Pin 1 | USB |
|---|---|---|---|
| 90° CW | **TOP row** | RIGHT | LEFT |
| 90° CCW | BOTTOM row | LEFT | RIGHT |

**Anything else is a reflection and cannot be built.** Revision A of this board
had the left column on top with pin 1 at the *left*, which is neither — the
transform from module coordinates to board coordinates had determinant −1. The
module would have had to be flipped over to fit, and every single pin was on
the wrong signal.

This board uses the first form: both sockets at rotation 270, pin 1 (`EN`
on the upper row, `IO23` on the lower) at the right-hand end, **USB pointing
left**.

### What is printed on the board

- a dashed **body outline** for the ESP32 and the TMC2209, so you can see the
  module's extent and which way it lies before fitting it
- a large **`USB <<<`** at the left-hand end of the ESP32 outline
- a bold **`1`** beside pin 1 of all four sockets
- the **signal name beside every pin** of both modules
- the orientation stated in words inside the outline, where it is covered once
  the module is in and visible exactly when you need it

If your module's pin 1 does not land next to the `1`, stop — do not force it.

## 7. Grounding and the two routing constraints

GND is a **pour on both layers**, so return paths are short and the sensitive
things (AS5600 I²C, the step pulse) sit over solid copper.

Two constraints the layout is built around, both worth knowing before you move
anything:

**Through-hole pin rows cannot be crossed.** At 2.54 mm pitch with ~1.7 mm
pads the gap between adjacent pads is 0.84 mm, and a 0.3 mm track with 0.3 mm
clearance needs 0.9 mm. Worse, a through-hole pad blocks *both* layers, so
there is no "go under it on the back" escape. The ESP32's two header rows are
therefore walls across the middle of the board.

**So the GPIO map is chosen to suit the geometry.** Everything whose
destination is the bottom connector strip lives on the ESP32's **lower** row;
everything serving the driver, the camera and the power input lives on the
**upper** row. That is why WAKE is on GPIO 4 rather than 33, and PPS on
GPIO 23 rather than 36 — see the revision note in FIRMWARE.md §4. Corridors at
x ≈ 35–42 mm and x ≈ 91–99 mm carry what is left, mostly the power rails, and
a horizontal channel below the lower row fans the bottom-strip signals out.

This is also why the board grew from the 127 × 76.2 mm that "3 × 5 inches"
would give, first to 127 × 84 and then to **150 × 100**. Each time the limit
was the same: nets with nowhere to fan out between the lower header row and
the bottom connector strip, and corridors too narrow at the module's ends.
The current size gives ~12 mm corridors and a 32 mm deep fan-out channel,
which is what finally made routing comfortable rather than marginal.

## 8. Jumpers

| Ref | Default | What it does |
|---|---|---|
| JP4 | **GND** | MS1 — TMC2209 UART address bit 0 |
| JP5 | **GND** | MS2 — UART address bit 1 |
| JP3 | open | bridges PDN_UART to the alternate StepStick pin, if your module puts UART on position 5 instead of 4 |
| J5 | wire | DIAG — no vendor brings StallGuard out on the 16-pin header, so run a flying lead from the module's DIAG pad to this header |

Both address jumpers to GND gives UART address 0, which is what the firmware
assumes. **The TMC2209's V<sub>REF</sub> pot is unused** — run current is set
over UART with IRUN/IHOLD.

## 9. Building it

```powershell
cd hardware
python gen_board.py                       # schematic + board + BOM
& 'C:\Program Files\KiCad\10.0\bin\python.exe' fill_zones.py
```

The KiCad project is **generated, not hand-drawn**. Edit the source, not the
`.kicad_pcb`:

| File | Holds |
|---|---|
| `design.py` | the netlist, every value, the ESP32/TMC pin maps |
| `place.py` | the floorplan: fixed positions and packing regions |
| `layout.py` | courtyard extents, the region packer, the collision check |
| `route.py` | the two-layer maze router |
| `gen_board.py` | emits `.kicad_sch`, `.kicad_pcb`, `.kicad_pro`, `BOM.csv` |
| `kicadlib.py` | S-expression reader/writer and library loader |

Regenerating overwrites the project, so any edit you make in KiCad's GUI is
lost on the next run. For one-off tweaks that is fine — open the project and
edit. For anything you want to keep, change `design.py` or `place.py`.

Checks that run every time:

- `layout.check()` fails the build on any courtyard overlap or off-board part
- `kicad-cli sch erc` — currently clean
- `kicad-cli pcb drc` — see §8

## 10. Known state

**Rev C**, generated 2026-09-27 for the 30-pin ideaspark module, fully routed,
and checked with KiCad 10's own tools:

| Check | Result |
|---|---|
| ERC | **0 violations** |
| DRC — unconnected | **0** |
| DRC — clearance / shorts / hole-to-hole | **0** |
| DRC — silkscreen overlap | 68 + 6 over-copper, cosmetic |
| Parts | 71 placed + 4 mounting holes |
| Nets | 45 |
| Routing | 234 track runs, 82 vias, GND poured both sides; complete on pass 12 of 30 |

The silkscreen warnings are reference designators colliding with each other
and with the module pin legends on a dense board. Nothing about fabrication
or assembly depends on them.

**The router is a greedy maze router with randomised restarts**, not a
commercial autorouter. With a fixed seed, `gen_board.py` reproduces the same
board every time. If you change the floorplan and a net comes out unrouted,
the message names it — raise `passes` in `route.py`, or open the board and
route that one by hand.

**Always run the DRC after regenerating**, and read the unconnected items: a
GND pad the pour cannot reach passes the router and ERC and only shows there.

### Getting the ground pour to reach every pad

Worth knowing if you move things. A pad can be fenced in by signal tracks on
both layers — and through-hole pads block both — leaving the pour unable to
reach it. What fixed that here, in order of how much it mattered:

1. **Tight thermals.** `thermal_gap` 0.3 mm and `thermal_bridge_width` 0.4 mm,
   with `min_resolved_spokes` set to 1. Going from the 0.5 mm defaults took
   isolated pads from 8 to 1. Thermal relief is kept rather than using a solid
   pour connection, because soldering a through-hole ground pin into solid
   1 oz copper is genuinely unpleasant.
2. **`GND_RESCUE` in `design.py`**: pads the router connects to their nearest
   GND pad *before* any signal is routed. Rev C names the four GND end pins of
   the bottom connector strip (J6.6, J7.5, J8.1, J8.4) — the lower-row signals
   fan out between them and fenced a different two in on every attempt until
   all four were reserved. The list comes from the DRC, which knows the pour;
   the router does not (reserving every pad the router *itself* could not
   stitch, eleven of them, left six signals unroutable).
3. **An explicit GND stitch**, routed last at signal width, twice, so a
   straggler can connect to track laid after its own first attempt.
4. **Ground on end pins.** Interior pins on a 2.54 mm connector are
   unreachable by the pour — the gap between adjacent pads is 0.84 mm and the
   pour needs about 1.25 mm — so ground belongs on an end pin.

### Drill spacing

The router keeps every via centre clear of every pad and via hole by the
fab's 0.25 mm hole-to-hole minimum, whatever the nets. Its copper checks alone
let a GND via land 0.19 mm from a GND pad's hole, which is legal copper and an
illegal drill.
## 11. Fabrication

2 layers, 1.6 mm, 1 oz copper, HASL — no controlled impedance, no fine pitch,
no blind vias. Minimum track 0.4 mm signal / 1.0 mm power, minimum clearance
0.3 mm, smallest drill 0.4 mm (vias). Any cheap fab will build this at their
default rules.

```powershell
$cli = 'C:\Program Files\KiCad\10.0\bin\kicad-cli.exe'
& $cli pcb export gerbers --output gerbers star_tracker_ctrl\star_tracker_ctrl.kicad_pcb
& $cli pcb export drill   --output gerbers star_tracker_ctrl\star_tracker_ctrl.kicad_pcb
```

## 12. Assembly order

Lowest parts first, and test each rail before fitting the next stage.

1. Resistors, diodes, small ceramics.
2. Q1, D2, F1, C1 — then **apply 12 V and check the rail at Q1's source**,
   and check that reversing the supply gives 0 V and nothing gets warm.
3. U2 (with its heatsink), L1, D3, C3, C5 — **check 5 V** before going on.
4. Q2, Q3, C7, the USB socket — pull GPIO 32's pad high by hand and confirm
   the camera rail switches.
5. Q4, Q5 and their four resistors — drive the socket's GPS_EN pin (GPIO 17) high by hand and
   confirm ~4.8 V appears on J9 pin 2, and 0 V when it is low.
6. Electrolytics, LEDs, connectors, sockets last.
7. **Fit the modules only after all rails read correctly.**

The 5 V rail feeds the ESP32's on-board regulator through the module's `5V`
pin, and everything at 3.3 V comes back out of the module's `3V3` pin. Added
3.3 V load is only ~20 mA (AS5600, DS3231, TMC2209 V<sub>IO</sub>, pull-ups),
which the module's AMS1117 handles without complaint.

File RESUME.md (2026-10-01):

# RESUME — where this stands and what is next

Last touched 2026-10-01.

> **PCB FROZEN — Rev C Gerbers were sent to the fab house (2026-10-01).**
> Do NOT modify `hardware/star_tracker_ctrl/`, `design.py`, `gen_board.py`,
> `place.py`, `route.py` or re-export Gerbers. Work around it in the build
> instead. Known workaround: L1 is a Murata `19R333C` (6.0 mm lead pitch) on
> the 5.0 mm `Fastron_11P` footprint; squeeze the leads 1 mm. The footprint
> name is cosmetic. Any real board change means a new revision (Rev D).
> Mouser order files: `hardware/mouser_passives.csv`, `mouser_semiconductors.csv`.
> Backorder substitution: Panasonic EEU-FR1E221 (C5) and EEU-FR1E101 (C11) were
> backordered at Mouser, and so was the proposed Nichicon `UHE1E221MPD`
> (`hardware/mouser_backorder_replacements.csv` is NOT ordered). Bought on
> **Amazon** instead (2026-10-01): Innfeeltech 220 uF / 25 V / 105 C aluminum
> radial electrolytic, 50-pack, general-purpose (ESR not stated). Use for C5
> and C11. **C11 is therefore 220 uF, not 100 uF** (a fine upsize, more VMOT
> bulk). If the driver resets or steps noisily, swap C11 for a low-ESR part
> first. Bend leads out to the 5 mm pads. `mouser_passives.csv` still lists the
> original Panasonic parts.

## Controller board Rev C — sent to fab

The blocker is gone. The pin check ran on the module in hand and the board
was redrawn for it:

```
chip ESP32-D0WD-V3  rev 300  2 core(s)  flash 4 MB
PSRAM: none
I2C scan:
  GPIO21 (SDA) / GPIO22 (SCL)  <- ESP32 default
      0x3C  SSD1306 OLED
  GPIO4  (SDA) / GPIO15 (SCL)  nothing
  GPIO5  (SDA) / GPIO4  (SCL)  nothing
```

- The OLED shares the sensor I²C bus on 21/22; `WAKE` stays on GPIO 4.
- No PSRAM (WROOM-class), so GPIO 16/17 are free.
- `hardware/design.py` carries the 30-pin map (FIRMWARE.md §4 is the table),
  `REV = "C"`. The GPS UART nets are named by direction
  (`ESP_TX_GPS_RX`, `GPS_TX_ESP_RX`), fixing Rev B's TX-to-TX wiring.
- Generated, routed, poured: **ERC 0, DRC 0 unconnected / 0 clearance / 0
  hole-to-hole**; only cosmetic silkscreen overlaps. PCB.md §10.
- Router changes this round: drill-to-drill keepout for vias, a two-pass GND
  stitch, and `GND_RESCUE` (named pads escaped before any signal).

### Next

1. Look over `hardware/board_top.png` and `hardware/schematic.pdf`; export
   Gerbers (PCB.md §11) and order.
2. Firmware slice 1 onward (FIRMWARE.md §0). The pin constants are §4.
3. Build per the assembly guide, `docs/assembly_guide/stjarnspar.pdf`.
## Module facts, measured and confirmed

| | |
|---|---|
| Board | ideaspark ESP32 + 0.96" OLED, silkscreen `ESP32 OLED-0.96 V3.0` |
| Module | ESP32-D0WD-V3 rev 3, 4 MB flash, no PSRAM (pin check 2026-09-27) |
| Pins | **15 per side, 30 total** |
| Pitch | **2.54 mm** — 14 gaps measured end-to-end as 35.56 mm |
| Row spacing | **27.94 mm** (1.1 in) — inside 27.27 + outside 28.90 → 28.09 measured |
| USB | at the **bottom**; EN button bottom-left, BOOT bottom-right |

### Pin layout — read off the silkscreen and confirmed by the user

Standard DOIT DevKit V1 layout. Note **VIN is on the left column and 3V3 on
the right**, opposite ends, unlike the 38-pin board.

| # | LEFT (J2) top→bottom | RIGHT (J1) top→bottom |
|---|---|---|
| 1 | EN | D23 |
| 2 | VP (GPIO36) | D22 |
| 3 | VN (GPIO39) | TX0 (GPIO1) |
| 4 | D34 | RX0 (GPIO3) |
| 5 | D35 | D21 |
| 6 | D32 | D19 |
| 7 | D33 | D18 |
| 8 | D25 | D5 |
| 9 | D26 | TX2 (GPIO17) |
| 10 | D27 | RX2 (GPIO16) |
| 11 | D14 | D4 |
| 12 | D12 | D2 |
| 13 | D13 | D15 |
| 14 | GND | GND |
| 15 | VIN | 3V3 |

## Mechanical Rev B -- done 2026-09-27

Writing the assembly guide turned up eight conflicts in the Rev A CAD. All are
fixed in the `.scad` and the docs:

| # | Rev A problem | Rev B |
|---|---|---|
| 1 | Tower cone sat inside the plate; the flange could not seat | Halves clamp the plate: flange above, Ø41 disc below, dowels across |
| 2 | Output shaft ran through the 1/4"-20 nut | Shaft cut to 55 mm, z -33 to 22 |
| 3 | M3x10 motor screws bottom out | M3x8 flat head |
| 4 | Motor screw heads and one M5 sit under the S1 wheel (2 mm) | Countersink them by hand; the plate is already cut |
| 5 | Lower hub rubbed the tower rim and the bearing's outer race | Printed washer on the inner race, hub 1 mm shorter |
| 6 | AS5600 bracket had no axial stop | Bracket stops on the disc; gap set by the parts |
| 7 | Grub holes in gears that turn on fixed nails | Removed from `stage` and `final_stage_gear` |
| 8 | 1/4"-20 nut pocket 2.2 mm deep | Upper hub 10 mm thick, 5.9 mm pocket; wheel screws are M3x20 |

## Still open

- **Is the OLED on the rotating camera platform or the fixed enclosure?** The
  camera sweeps ~180° a night and the enclosure does not, so "display opposite
  the lens" only holds at one point in the sweep if the panel is fixed.
  `oled_on_while_tracking` currently defaults to on.
- **Solder the GPS PPS flying lead.** The GY-NEO6MV2's 4-pin header does not
  bring TIMEPULSE out; tap it at the on-board PPS LED.
- The three HERO6 unknowns in HARDWARE.md §6 are still unmeasured.

## Where things are

| | |
|---|---|
| `README.md` | project overview, written as a resume doc |
| `FIRMWARE.md` | firmware architecture, state machine, pin map, build order |
| `HARDWARE.md` | electronics architecture and BOM |
| `hardware/PCB.md` | board design notes, orientation rules, assembly order |
| `hardware/*.py` | the generator: design → place → layout → route → gen_board |

The KiCad project is **generated, not hand-drawn**. Edit `design.py` and
`place.py`; anything done in the GUI is lost on the next run.

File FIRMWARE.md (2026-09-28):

# Firmware — implementation plan and status

Companion to **[HARDWARE.md](HARDWARE.md)**. This file is the resumable one: it
carries the architecture, the decisions already made, the pin map as built, and
the slice-by-slice build order. **HARDWARE.md §5 is superseded by §4 here** —
that table predates the OLED board and the DS3231 interrupt line.

**Status: nothing written yet beyond the timing core.** Slice 0 is next.

---

## 0. Where this stands

| Slice | What | Blocked on | State |
|---|---|---|---|
| 0 | Board bring-up: verify the actual pinout, PlatformIO env | — | **next** |
| 1 | `motion/` — step engine, position counter, both rate profiles | slice 0 | not started |
| 2 | `app/fsm` + fake camera + host-side simulator | — | not started |
| 3 | `hal/` — DS3231, AS5600, TMC2209 UART, battery, OLED, deep sleep | modules on hand | not started |
| 4 | Schedule parse/validate + solar solver (host-tested) | — | not started |
| 5 | Web server, status JSON, static UI, config AP | slice 2 | not started |
| 6 | Real GoPro driver + `discover`; answers the 3 hardware unknowns | HERO6 | not started |

Slices 2 and 4 need no hardware at all and are unit-testable on the laptop.
Start slice 0 and slice 2 in parallel if you want to move fast.

`firmware/sidereal_drive/sidereal_drive.ino` stays where it is as the reference
artefact. Its accumulator migrates into `lib/motion/`; the sketch is not the
build target.

---

## 1. Decisions taken (and why) — 2026-09-17

| # | Decision | Rationale |
|---|---|---|
| D1 | **Position-servo step engine, not deadline-based** | Jitter is free, lost steps are not. Servoing to a computed position makes the drive immune to WiFi stalls and gives free mid-night resume. §2 |
| D2 | **Tracking is the mission; the camera is best-effort** | Bench repeatability runs need tracking with no camera at all, and other camera bodies are coming. Camera failure logs and continues. §3 |
| D3 | **Rewind for v1**, forward-only noted as the better end state | Forward-only removes every direction reversal but needs the slip ring. A slack cable loop is the v1 reality and the cable must not bind. |
| D4 | **DS3231 INT on GPIO 33**, wired-OR with the config button | Was missing from the pin map entirely. Deep sleep cannot be woken by an alarm that is not connected to anything. §4 |
| D5 | **On-device solar computation**, with absolute-UTC override | Makes the 3-day schedule an override on indefinite operation, which is what justifies the solar panel. §5 |
| D6 | **Camera setting IDs live in a data file**, never in code | The HERO6 gpControl tree is unmeasured. A `discover` command dumps it; firmware reads a profile. Unblocks all firmware work now. §6 |
| D7 | **Status by 1 Hz polling of one JSON struct** | A dropped SSE stream looks identical to "nothing is happening" — the worst failure mode to make invisible on an unattended device. §7 |
| D8 | **AP up during TRACK**, config flag, default on while debugging | ~100 mW, ~1.2 Wh of a 43 Wh night. The GoPro does not need the radio once the shutter is running. |
| D9 | **PlatformIO, not the Arduino IDE** | Host-side unit tests (`platform = native`) are the only way to validate a 3-night schedule without waiting 3 nights. §8 |

| D10 | **GPS is the time and position authority; the DS3231 stays** | A GPS cannot wake a sleeping ESP32 at a time, needs sky view and ~45 mA just to know the time, and has nothing to say under cloud. The RTC is the bootstrap; the GPS disciplines it. §5 |

### GPS — now in v1 (was deferred)

A GPS module solves time authority and site coordinates in one part, and a
magnetometer helps the polar alignment that the README says dominates everything.

Module: **GY-NEO6MV2** (u-blox NEO-6M). PPS on **GPIO 23**, UART on
**GPIO 5 / 18** (nets named by direction), power switch on **GPIO 17**. A compass (QMC5883L `0x0D` or
HMC5883L `0x1E`) still drops onto the existing I²C bus, and stays v2.

> ### Wiring note: the GY-NEO6MV2 does not break out PPS
>
> Its header is four pins, `VCC RX TX GND`. The NEO-6M's TIMEPULSE output
> drives the on-board PPS **LED** rather than a pin. J9 on the controller
> board is laid out so the module's 4-wire cable plugs into pins 2–5 and
> **PPS is a fifth pin you solder a flying lead to**, tapped at that LED.
> Check your own board first — some revisions do bring a PPS pad out.
>
> Be honest about what PPS buys here. It sets the RTC to sub-second accuracy
> and it *measures* the crystal's true ppm error. It does **not** meaningfully
> improve tracking: 20 ppm over a 12 h night is 3.6 arcsec at the output, and
> polar alignment error is three orders of magnitude larger. PPS is an
> instrument here, not a control input, and it must never correct step
> *phase* mid-track — see the rule in §5.

---

## 2. Motion: one ISR, one position counter, two rate profiles

Four layers. The boundary that matters is between the top two:

```
  app/     state machine, schedule, policy          core 0, soft realtime
  net/     web server, GoPro client, WiFi mode      core 0, blocking allowed
  ----------------------------------------------------------------
  motion/  position counter, rate profiles, ISR     core 1, hard realtime
  hal/     TMC2209, AS5600, DS3231, OLED, ADC       either
```

**The step generator must be unable to lose a step no matter what the WiFi stack
does.** `WiFi.begin()`, DNS and `HTTPClient` block for tens to hundreds of ms
inside the Arduino stack. At 152 steps/s a 200 ms stall is 30 dropped steps —
3 arcsec of permanent output error that nothing downstream can detect.

### The inversion

Do not ask "is a step due?". Ask "where should I be?":

```
target_usteps(t) = (elapsed_us * USTEPS_PER_REV) / SIDEREAL_US   // 64-bit, exact
while (pos_usteps < target_usteps) emit_one_step();
```

Same Bresenham arithmetic as the existing sketch, different subject. Block it for
200 ms and it emits 30 pulses back to back and is exactly where it should be.

Consequences worth naming:

- **Self-healing against any core-0 stall.** No critical sections around WiFi.
- **Tracking and slew become one mechanism** with two `target()` functions. One
  position counter, one place that touches DIR, no handoff seam.
- **Mid-night resume is free.** Reboot at 02:00, read the encoder, recompute
  `target` from `now - start_time`, catch up in one slew. You lose frames, not
  the night. This is impossible with a deadline-based stepper.

Implementation: a GPTimer ISR at a fixed **20 kHz tick pinned to core 1**,
emitting at most N pulses per tick. 50 µs of jitter, which is 0.0008 arcsec of
sidereal motion. Irrelevant.

### Two rate profiles

| | Tracking | Slew (orient / rewind) |
|---|---|---|
| Rate | 152.13 usteps/s | ~6.7 kHz pulses |
| MRES | 1/32 | **1/8** (set over UART) |
| Target fn | Bresenham vs. sidereal clock | trapezoid ramp to a position |
| Duration | 12 h | ~4.1 min for 180.5° |

180.5° of output is 1024 motor revolutions. At 1/32 that is 6.55 M pulses and
would need 27 kHz. At 1/8 it is 1.64 M pulses at 6.7 kHz — and the TMC2209's
MicroPlyer interpolates to 1/256 internally regardless, so nothing is lost.

> **Trap: `pos_usteps` must stay in one canonical unit.** Keep it in 1/32 units
> always; a 1/8 pulse advances it by 4. Do not let the counter's meaning change
> with MRES. That works on the bench and loses a revolution at 3 a.m.

### Backlash discipline lives in exactly one function

```
moveToForward(int64_t target_usteps)   // the ONLY thing that writes DIR
```

If the move would arrive travelling in reverse, overshoot past the target by
`BACKLASH_USTEPS` and come back forward. Nothing else may set direction.

| Quantity | Value |
|---|---|
| Output backlash (final mesh, 0.35 mm / 96 mm) | 3.6 mrad ≈ **750 arcsec** = 0.208° |
| usteps per output degree | 36,409 |
| `BACKLASH_USTEPS` | ~7,600 → **use 10,000** for margin |
| Overshoot cost at slew | 2,500 pulses ≈ 0.37 s |

750 arcsec is the largest correctable error in the machine and it is entirely a
software discipline problem. With D3 (rewind), every single night crosses it.

### Travel envelope is a hard limit, enforced in firmware

12 h of tracking is **180.5°** of output rotation. With a slack cable loop rather
than a slip ring, the cable sets a physical arc. The firmware must refuse a
schedule that would run past it rather than discover it at 4 a.m. by pulling the
USB-C out of the camera.

`TRAVEL_MIN_DEG` / `TRAVEL_MAX_DEG` are **compile-time constants**, not schedule
fields. A phone must not be able to widen them. Measure the real arc once the
cable is routed and set them then.

> **Encoder wrap:** the AS5600 is 12-bit over one revolution and the output turns
> <1 rev per night. Orient the magnet so the 180.5° working arc does not cross
> the 0/4095 boundary — put the start near raw 90° so the sweep ends near 271°.
> Then no wrap handling is needed anywhere.

---

## 3. State machine

The camera path is a **best-effort side branch**, not a gate (D2).

```
                        +--------------------------------------+
  power on              |                                      |
    |                   |                                      |
    v                   |                                      |
  BOOT --> HOME --> IDLE (deep sleep; GPIO33 wake armed)        |
           |         |  ^                        radio: OFF    |
    encoder bad      |  +---------- button --> CONFIG_AP -------+
           |         |                         radio: AP
           v         |  RTC alarm, start - lead               timeout 10 min
         FAULT       v
           ^     PREFLIGHT   battery, encoder, schedule, envelope check
           |         |       radio: OFF            deadline 10 s
           |         v
           |     TIME_SYNC   GPS on, wait for fix, set DS3231, GPS off
           |         |       radio: OFF            deadline 120 s
           |         |       no fix -> log it, keep the RTC, carry on
           |         v
           |      ORIENT     moveToForward(start_angle)
           |         |       radio: OFF            deadline 6 min
           |         v
           |    +- CAM_SEQUENCE ------------------------------+
           |    |  CAM_POWER -> CAM_WAKE -> CAM_CONFIG -> START|
           |    |  radio: STA(gopro)      deadline 150 s total |
           |    |                                              |
           |    |  any failure, or camera_policy == none:      |
           |    |  log, set camera.result, DROP THROUGH -------+--+
           |    +--------------------+-------------------------+  |
           |                         v                            |
           |                      TRACK  <--------------------------+
           |                         |    accumulator running
           |                         |    radio: OFF or AP (D8)
           |                         |
           |   stall / encoder divergence / battery low / envelope
           |                         +----------------> SAFE_STOP
           |                         v stop_time reached        |
           |                      CAM_STOP   best-effort, 30 s  |
           |                         |       radio: STA(gopro)  |
           |                         v                          v
           |                      REWIND <----------------------+
           |                         |  moveToForward(start), deadline 8 min
           |                         v
           +---- mechanical ----  write night report, re-arm alarm --> IDLE
```

### `camera_policy` — the D2 knob

| Value | Behaviour |
|---|---|
| `none` | CAM_SEQUENCE skipped entirely. **Bench repeatability runs.** |
| `best_effort` | **Default.** Failure is logged, the night tracks anyway. |
| `required` | Failure means the night is abandoned, back to IDLE. |

A schedule night may override the global default. `required` exists for the
future case where the frames are the whole point and 9 Wh of tracking without
them is waste; it is not the default now.

### Rules baked into the FSM

- **Every state has a wall-clock deadline** whose expiry leads somewhere safe.
  The deadline is checked in the FSM tick, never inside a network call. A
  `WiFi.begin()` against a camera that never woke sits there forever otherwise.
- **`SAFE_STOP` is not `CAM_STOP`.** The abort path stops the motor *first*, then
  deals with the camera best-effort with short timeouts — whatever triggered the
  abort may be the same thing hanging the network.
- **FAULT is only for damage or impossibility**: encoder not responding at boot,
  commanded/encoder divergence past threshold, travel envelope violation. Camera
  trouble, low battery and a bad schedule are all *skipped nights*, not faults.
- **Persist on transition, not on tick.** `{state, pos_usteps, night_index,
  last_completed_utc, fault_code}` to NVS. A dozen writes a night — nothing for
  flash wear.
- **Persist position even though the encoder is absolute.** A disagreement
  between "where I thought I was" and "where the magnet says I am" is the single
  most informative diagnostic this machine can produce: it means the train
  slipped or a coupling let go.

### Divergence thresholds

| | Value |
|---|---|
| AS5600 resolution | 0.088° |
| Backlash | 0.208° |
| **Warn** (log, keep tracking) | 0.5° |
| **Fault** (SAFE_STOP) | 2.0° |

### TIME_SYNC — and why it is not allowed to fail

On entry it powers the GPS (GPIO 17), reads NMEA until it has a 3-D fix with a
sane HDOP, then:

1. **Sets the DS3231** from GPS UTC and records `rtc_drift_s` — how far the
   RTC had wandered since the last sync. That residual is a free nightly
   measurement of your crystal, and it is what turns "±2 ppm nominal" into a
   number you actually know.
2. **Takes latitude and longitude** from the fix and uses them for tonight's
   twilight calculation, overriding `site` in the schedule. The tracker
   becomes location-aware — move it and the times follow.
3. **Optionally measures PPS**: count `esp_timer` microseconds across N pulse
   edges to get the crystal's real ppm error.
4. **Powers the GPS down.** It draws 30–45 mA and has nothing to do until
   tomorrow.

`gps_policy` mirrors `camera_policy` and defaults to **`best_effort`**: no fix
in 120 s means log it, keep the DS3231's time and the last known position, and
track anyway. A GPS that cannot see sky must never cost you a night — which is
exactly why the RTC is still on the board.

### Bench commands that serve D2

- `POST /api/command {test_track, duration_min}` — enter TRACK immediately with
  `camera_policy: none`. Straight repeatability of the drive.
- `POST /api/command {repeat_test, cycles, track_min}` — N × (orient → short
  track → rewind → read encoder at the start angle). Reports mean and σ of the
  **return error in arcsec**. This measures backlash discipline, train
  repeatability and slip in one number, and it is the number that tells you
  whether `BACKLASH_USTEPS` is right.

### Radio mode is a state attribute, never set ad hoc

`WIFI_AP_STA` exists but the AP and STA **must share a channel**. When the STA
joins the GoPro's AP, the softAP silently hops to the GoPro's channel and every
connected phone drops. Do not treat AP+STA as a capability. One function
transitions `radio_mode`; the state table declares what each state requires.

---

## 4. Pin map — as built

**Board: ideaspark ESP32 + 0.96" SSD1306 OLED, 30-pin (DOIT DevKit V1 layout),
CH340, micro-USB. Controller PCB Rev C.** This table is generated into the
board from `hardware/design.py` (`ESP32_LEFT` / `ESP32_RIGHT`); change it there.

> ### Pin check result (2026-09-27, `firmware/pincheck`)
>
> Chip ESP32-D0WD-V3 rev 3, dual core, 4 MB flash, **no PSRAM** (WROOM-class,
> so GPIO 16/17 are free). The on-board **OLED answers at `0x3C` on GPIO 21/22**
> and nothing answers on 4/15 or 5/4 -- the OLED shares the sensor I²C bus
> (`0x3C`, `0x68`, `0x36` coexist) and GPIO 4 stays free for `WAKE`.

The module's **left column is the board's upper row** (driver, camera, divider,
status LED) and its **right column the lower row** (everything bound for the
bottom connector strip). Through-hole pin rows cannot be crossed, so this split
is structural, not cosmetic -- see *Why the rows matter* below.

| GPIO | Net | To | Notes |
|---|---|---|---|
| 25 | `STEP` | TMC2209 STEP | upper row |
| 26 | `MOT_DIR` | TMC2209 DIR | upper row; written only by `moveToForward()` |
| 27 | `TMC_EN` | TMC2209 EN | upper row; active low |
| 33 | `ESP_TX` | TMC2209 PDN_UART via R7 1 kΩ | upper row; single-wire UART, ESP32 transmits |
| 14 | `TMC_UART` | TMC2209 PDN_UART, direct | upper row; ESP32 receives |
| 36 | `TMC_DIAG` | TMC2209 DIAG (J5 flying lead) | upper row; StallGuard. Input-only, R9 10k pull-down |
| 32 | `CAM_EN` | camera 5 V switch, Q3 -> Q2 | upper row |
| 34 | `VBAT_SENSE` | R14/R15 divider | upper row; input-only, **no internal pull-up** |
| 13 | `LED_ST` | status LED3 via R8 | upper row |
| 39, 35 | `SPARE39`, `SPARE35` | spare header J11 | upper row; both input-only |
| 21 | `SDA` | I²C: DS3231 `0x68`, AS5600 `0x36`, OLED `0x3C`, J10 | lower row |
| 22 | `SCL` | I²C | lower row; run the bus at 400 kHz |
| **4** | `WAKE` | DS3231 INT + config button SW1 | lower row; wired-OR, R12 4.7 kΩ pull-up. RTC-capable (`ext0`) |
| 19 | `HOME` | opto home flag J8 | lower row; R13 10 kΩ pull-up |
| 23 | `PPS` | GPS PPS (J9 pin 1) | lower row |
| **5** | `ESP_TX_GPS_RX` | J9 pin 3, the module's RXD | lower row; ESP32 transmits. Strapping pin, idles high as TX |
| **18** | `GPS_TX_ESP_RX` | J9 pin 4, the module's TXD | lower row; ESP32 receives |
| **17** | `GPS_EN` | GPS 5 V switch, Q5 -> Q4 | lower row; GPS off while it floats at boot |
| 16, 15 | -- | free | lower row; 15 is a strapping pin |
| 2 | -- | **avoided** | must be low to enter download mode; a pull-up breaks USB flashing |
| 12, 0, 1, 3 | -- | unused | 12/0 strapping, 1/3 = USB serial |
| -- | *compass (v2)* | I²C, `0x0D` / `0x1E` | no conflict |

> ### What changed from Rev B (the 38-pin board)
>
> | Signal | Rev B | Rev C | Why |
> |---|---|---|---|
> | TMC UART (`ESP_TX` / `TMC_UART`) | 17 / 16, lower row | **33 / 14, upper row** | the driver is on the upper side; no crossing |
> | `TMC_DIAG` | 39 | **36** | both input-only; 36 is where the 30-pin row puts it |
> | `LED_ST` | 15, lower row | **13, upper row** | beside its LED, and off a strapping pin |
> | `GPS_EN` | 2 | **17** | GPIO 2 must stay free for download mode |
> | GPS UART nets | `GPS_TX` / `GPS_RX` (TX wired to TX) | **`ESP_TX_GPS_RX` / `GPS_TX_ESP_RX`** | named by direction; ESP32 TX now reaches the module's RXD |
> | Spare header J11 | 6 pins: 33, 14, 13, 36 | **4 pins: 39, 35** | the upper row's two free pins |
>
> `WAKE` (4), `PPS` (23), `HOME` (19), I²C (21/22), `STEP`/`DIR`/`EN`
> (25/26/27), `CAM_EN` (32) and `VBAT_SENSE` (34) are unchanged.

> ### Why the rows matter
>
> On a through-hole board the ESP32's two header rows are **walls**: 2.54 mm
> pitch with ~1.7 mm pads leaves a 0.84 mm gap, and a 0.3 mm track needs
> 0.9 mm to pass legally -- so no signal can cross a pin row *on either
> layer*, because through-hole pads block both. Everything crossing has to go
> the long way round the module's ends. So nothing is made to cross: signals
> bound for the bottom connector strip live on the lower row, and everything
> serving the driver, the camera and the power input on the upper row.
Avoid GPIO 6–11 (flash) and 0 / 12 / 15 (strapping).

### The GPIO 4 wired-OR — why one pin takes both wake sources

ESP32 `ext0` wakes on **one** pin. `ext1` offers `ALL_LOW` or `ANY_HIGH`, and two
independent active-low sources fit neither. The clean answer needs no extra parts:

**The DS3231 INT is open-drain and a button to ground is effectively open-drain.
Tie both to GPIO 4 with a single 4.7 kΩ pull-up.** Either one pulls the line low
and wakes the ESP32 through `ext0`.

Disambiguate in software on wake:

```
read DS3231 status register
  alarm flag set   -> it was the alarm; clear the flag
  flag clear       -> it was the button
```

The second input pin this section originally called for has been dropped: a
two-terminal switch cannot drive two nets, and the software already tells the
two sources apart from the alarm flag. One pin, one pull-up, zero extra parts.

### The OLED

An asset — it means you can see what the machine is doing without a phone. Two
rules:

- **Display during TRACK is a config flag, `oled_on_while_tracking`.** It is a
  blue-white light source near a lens doing wide-field astrophotography, so the
  default was off. With the panel mounted on the **underside of the faceplate,
  facing away from the lens**, leaving it on is a reasonable call and the flag
  defaults to on for this build.

  > One geometric caveat before you rely on it. The camera rotates through
  > ~180° over a night and the enclosure does not. If the display is fixed to
  > the baseplate, "opposite the lens" holds at **one point in the sweep** —
  > by dawn the lens has swung 180° round and may be looking back toward it.
  > If the display rides on the rotating camera platform, the geometry holds
  > all night. Worth checking which one you have; if it is the fixed case,
  > dimming the panel or blanking it after 30 s of no button press keeps the
  > diagnostic value without the risk.
- **Issue the SSD1306 display-off command before deep sleep.** The panel draws
  even when the content is static.

Cost when on: ~0.05 W, ~0.6 Wh over a night. Update at 1–2 Hz, not faster — a
full 1024-byte frame at 400 kHz is ~26 ms of bus time. That blocks the I²C task
but **not** the step ISR, which never touches I²C.

Suggested pages, cycled by the button: `STATE + countdown` / `encoder angle + AGC
+ magnitude` / `battery + RTC` / `last night result`.

### Wiring rules that kill drivers if ignored

100 µF low-ESR across VMOT right at the TMC2209; common ground between ESP32 and
driver; never unplug the motor with power applied; TMC2209 VDD from **3.3 V**,
not 5 V.

---

## 5. Time, schedule, and validation

### Two clocks, never mixed

| Clock | Job | Why |
|---|---|---|
| **DS3231** | wall clock, alarms, schedule | ±2 ppm, battery-backed, survives deep sleep |
| **`esp_timer`** | step phase within one night | 64-bit µs, monotonic, ±20 ppm crystal |

The ESP32's own RTC in deep sleep runs off a ~150 kHz RC oscillator at roughly
±5% — ±40 minutes across a winter day. Useless for "wake at dusk". The DS3231 is
not optional.

> **Rule: never discipline the step accumulator to the DS3231.** A 1-second
> resolution reference correcting a 20 ppm crystal injects far more error than it
> removes. Wall clock and step phase are separate concerns; coupling them is how
> you get a drift bug you cannot reproduce. (A GPS PPS edge *can* legitimately
> discipline the rate in v2 — 1 ppm in a few minutes of averaging — but even then
> it corrects **rate between nights**, never **phase mid-track**.)

For scale: 20 ppm over a 12 h run is 0.86 s = **3.6 arcsec** at the output,
accumulated across the whole night. Three orders of magnitude below polar
alignment error. Leave it alone.

### Schedule format — intent, not just timestamps (D5)

```json
{
  "version": 1,
  "site": { "lat": 0.0000, "lon": 0.0000, "tz_offset_min": -480 },
  "defaults": {
    "start": { "event": "dusk_astronomical", "offset_min": 10 },
    "stop":  { "event": "dawn_astronomical", "offset_min": -10 },
    "start_angle_deg": -90.0,
    "camera": "nightlapse_30s_iso800",
    "camera_policy": "best_effort"
  },
  "nights": [
    { "date": "2026-09-18" },
    { "date": "2026-09-19", "start": { "utc": "2026-09-20T04:15:00Z" } },
    { "date": "2026-09-20", "skip": true }
  ],
  "repeat_after_list": true
}
```

`site` is a placeholder — put your own latitude and longitude in before the
first night, because the twilight times are computed from them.

The NOAA solar position algorithm is ~40 lines of `double` and resolves twilight
to well under a minute — ample against the lead time. `repeat_after_list` is what
keeps the device running past the three explicit nights, which is what makes the
solar panel worth having. An explicit `utc` overrides the computed event.

### Validation — four layers, and the fourth is the one that matters

1. **Parse.** ArduinoJson, fixed document size. Reject oversized input before it
   touches the filesystem.
2. **Schema and range.** lat ∈ [−90, 90], offsets ±180 min, known camera profile
   name, known `camera_policy`.
3. **Semantic.** stop > start; duration < 16 h; nights ascending and
   non-overlapping; date resolves to a real date.
4. **Mechanical envelope.**
   `start_angle + duration × sidereal_rate ≤ TRAVEL_MAX_DEG`.
   A schedule that fails this is hardware-damaging. Refuse it at upload with a
   readable reason.

Validation runs **at upload** — returning the full error list so you fix it on the
phone — **and again at every boot**, because half-written flash is exactly the
failure mode the ESP32 was chosen to survive.

**High-latitude edge case:** astronomical twilight has *no solution* above ~49°
in summer. The solver must return "no such event" rather than a garbage number.
Policy: fall back to nautical, then civil, then skip the night with a logged
reason.

### Storage

LittleFS, written atomically — `schedule.json.tmp` → fsync → rename. Keep
`schedule.good.json` as the last version that both validated *and* survived a
full night, and fall back to it on load failure. A device that comes up after a
brownout with a corrupt schedule and no fallback does nothing until you drive out
to it.

---

## 6. Camera layer (D6)

**Never hardcode a gpControl setting ID.** `camera_profile.json` on LittleFS maps
logical names to whatever this specific HERO6 firmware uses:

```json
{
  "model": "HERO6", "fw": "<from status>",
  "mac": "AA:BB:CC:DD:EE:FF",
  "commands": {
    "shutter_on":  "/gp/gpControl/command/shutter?p=1",
    "shutter_off": "/gp/gpControl/command/shutter?p=0",
    "sleep":       "/gp/gpControl/command/system/sleep",
    "mode_nightlapse": "/gp/gpControl/command/mode?p=0&sub_mode=4"
  },
  "settings": {
    "nightlapse_shutter":  { "id": 31, "values": { "30s": 8 } },
    "nightlapse_interval": { "id": 32, "values": { "continuous": 0 } },
    "iso_max":             { "id": 24, "values": { "800": 3 } }
  },
  "status_keys": { "recording": 8, "battery": 2, "sd_remaining": 54 }
}
```

**Those IDs are placeholders.** The `discover` command joins the camera,
`GET /gp/gpControl`, dumps the whole settings tree to LittleFS and serves it at
`GET /api/camera/dump`. Read it on the laptop, fill in the profile, done — that
is HARDWARE.md open item #1 turned into a firmware feature you run once.

A `Camera` interface with three implementations:

| Impl | Use |
|---|---|
| `GoProHero6` | the real thing, over `gpControl` |
| `FakeCamera` | canned status — everything above the interface is testable today |
| `NoCamera` | `camera_policy: none`; bench runs, and the seam where other bodies land (D2) |

The other two hardware unknowns become **config, not code**:

- **Standby draw** → boolean `camera_rail_off_during_day`. The GPIO 32 load
  switch already exists to make this a runtime choice. Measure later, flip it.
- **Does WoL work** → `CAM_WAKE` sends the magic packet 3×, then power-cycles the
  rail via GPIO 32 and retries. If WoL turns out unreliable, the rail cycle *is*
  the wake mechanism and the state machine does not change shape.

> **New unknown to verify early:** does the HERO6 keep its AP up and rejoinable
> after the ESP32 disconnects mid-record? If it drops WiFi while recording, the
> dawn stop cannot be issued and the fallback is cutting the load switch — which
> loses the last file. Cheap to test, and it changes the design.

---

## 7. Status and API (D7)

```
GET  /api/status          the struct, ~1 Hz polling
GET  /api/schedule        current, plus validation state
PUT  /api/schedule        upload; 200 + normalized, or 422 + error list
POST /api/command         {jog, goto, home, stop, test_track, repeat_test,
                           test_camera, discover, sleep_now}
GET  /api/log?since=N     ring buffer, NDJSON
GET  /api/night/last      last night report;  /api/night/list for the last 10
GET  /api/camera/dump     raw gpControl tree
POST /api/time            set DS3231 from the browser's clock
```

**Polling, not WebSocket, not SSE.** 1 Hz GET of ~400 bytes. A phone that locks
its screen, a backgrounded tab or a client walking out of range all recover with
zero connection state.

**The page is static.** `index.html` gzipped on LittleFS, far-future cache
headers, all dynamics from `/api/status`. No templating, no string building in
C++, and the UI can be developed against a mock JSON file in a browser with no
ESP32 attached.

### The status struct is the contract

```
state, state_entered_s, deadline_remaining_s, fault_code, fault_text,
pos_usteps, pos_deg, encoder_deg, encoder_err_deg, encoder_agc, encoder_magnitude,
tracking_elapsed_s, tracking_remaining_s, target_minus_actual_usteps,
rtc_utc, rtc_temp_c, rtc_lost_power, rtc_drift_s,
gps: { policy, powered, fix, sats, hdop, lat, lon, utc, pps_ppm, last_error },
battery_v, battery_pct,
camera: { policy, powered, awake, recording, battery_pct, sd_free_mb, last_error },
schedule: { valid, nights_loaded, next_start_utc, next_stop_utc, source },
radio: { mode, ssid, rssi, clients },
uptime_s, boot_count, free_heap, littlefs_free
```

Three fields earn their place specifically:

- **`encoder_agc` / `encoder_magnitude`** — the AS5600 reports "too far / too
  close" as a number. Put them on the front page of the UI *and* on the OLED
  during assembly. It converts an eyeballed air gap into a reading.
- **`target_minus_actual_usteps`** — the servo error from §2. Steady state
  oscillates 0–1. Anything large means something is starving the step task, and
  there is no other way to see it.
- **`camera.policy`** — so a bench run that is deliberately camera-less is never
  mistaken for a camera that failed.
- **`rtc_drift_s` and `gps.pps_ppm`** — the two numbers that tell you what your
  timebase is actually doing, rather than what the datasheet claims. Watch them
  across a few nights before deciding the clock needs any correction at all.

### The night report is the real product

You are asleep while this runs. On entering IDLE, write one JSON record: planned
vs. actual start/stop, max encoder divergence, min battery voltage, camera
battery at start and end, frame count if status exposes it, `camera.result`, and
every warning. When the tracker does something odd on Tuesday you want Tuesday's
file, not a guess.

---

## 8. Build setup — PlatformIO (D9)

```
firmware/
  platformio.ini
  src/main.cpp
  include/config.h            pins, travel limits, thresholds — one place
  lib/
    motion/    StepEngine, RateProfile, moveToForward
    hal/       Ds3231, As5600, Tmc2209, Battery, Oled, LoadSwitch
    app/       Fsm, Schedule, Solar, Status, NightLog
    net/       WebApi, RadioMode, Camera + GoProHero6 / FakeCamera / NoCamera
  data/        index.html.gz, schedule.json, camera_profile.json
  test/
    test_solar/  test_schedule/  test_fsm_sim/
  sidereal_drive/sidereal_drive.ino    reference artefact, not a build target
```

```ini
[env:esp32-oled]
platform      = espressif32
board         = esp32dev
framework     = arduino
monitor_speed = 115200
upload_speed  = 460800            ; CH340 — drop to 115200 if uploads fail
board_build.filesystem = littlefs
build_flags   = -DCORE_DEBUG_LEVEL=3
lib_deps =
  bblanchon/ArduinoJson @ ^7.1.0
  teemuatlut/TMCStepper @ ^0.7.3
  adafruit/Adafruit SSD1306 @ ^2.5.9
  adafruit/Adafruit GFX Library @ ^1.11.9
  mathieucarbou/ESPAsyncWebServer @ ^3.1.0

; Host-side tests. This is the env that makes a 3-night schedule
; validate in seconds instead of three days.
[env:native]
platform       = native
test_framework = unity
build_flags    = -DSIM_BUILD -std=gnu++17
```

Write the **AS5600 driver by hand** (~30 lines of raw I²C). The libraries mostly
omit `AGC` and `MAGNITUDE`, which are the two registers that make the magnet gap
measurable rather than guessed.

Filesystem upload is `pio run -t uploadfs` and is a **separate step** from the
firmware upload — easy to forget after editing `data/`.

CH340 notes: Windows needs the CH340 driver; set `upload_port = COMx` if
auto-detect picks the wrong port; if the auto-reset circuit misbehaves, hold BOOT
during the "Connecting..." dots.

### The simulator is the thing to push hardest on

`test_fsm_sim` runs the FSM on the host against a fake clock at 1000×, a
`FakeCamera` and a fake encoder. You cannot debug a 3-day schedule in real time,
and every bug in this device manifests between midnight and dawn when you are not
watching. Cases that belong in it from day one:

- camera fails at every stage → night still tracks (D2)
- brownout at 02:00 → resume mid-track at the right position
- schedule that violates the travel envelope → refused
- astronomical twilight with no solution → falls back, then skips with a reason
- stop_time crosses a DST boundary / a month end / a year end
- battery drops below threshold mid-track → SAFE_STOP, camera stopped, rewound

---

## 9. Open items

**Firmware**

- [x] ~~**Slice 0, step 1: verify the OLED board pinout**~~ -- done 2026-09-27: OLED on 21/22, no PSRAM (§4)
- [x] ~~Confirm the module is WROOM-32, not WROVER~~ -- pin check 2026-09-27: no PSRAM
- [ ] Measure the real cable arc, set `TRAVEL_MIN_DEG` / `TRAVEL_MAX_DEG`
- [ ] Set `BACKLASH_USTEPS` from a `repeat_test` run, not from the 0.35 mm estimate
- [ ] Choose the AS5600 magnet orientation so the working arc clears the 0/4095 wrap

**Hardware** — carried from HARDWARE.md §6

- [ ] Dump `/gp/gpControl` from the actual HERO6 → fills `camera_profile.json`
- [ ] Measure HERO6 standby draw → sets `camera_rail_off_during_day`
- [ ] Confirm WoL wakes the camera reliably
- [ ] **New:** does the HERO6 keep its AP rejoinable after the ESP32 disconnects
      mid-record? (§6)
- [ ] Cable routing for 180.5° of sweep — slack loop (v1) vs slip ring
- [ ] Battery vs battery + solar

**GPS (now v1)**

- [x] ~~GPS module~~ — GY-NEO6MV2 on the board: PPS on GPIO 23, UART on 5/18,
      switched 5 V feed on GPIO 17
- [ ] **Solder the PPS flying lead** at the module's PPS LED — its 4-pin header
      does not bring TIMEPULSE out (§1)
- [ ] Mount the antenna where it can see sky; the IP54 box will not pass it
- [ ] Implement `TIME_SYNC` and watch `rtc_drift_s` for a few nights before
      deciding the clock needs any correction at all

**v2**

- [ ] Compass on the existing I²C bus for polar alignment assist
- [ ] Slip ring → forward-only operation, no direction reversal ever (D3)

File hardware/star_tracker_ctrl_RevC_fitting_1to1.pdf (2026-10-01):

## Star tracker controller Rev C - 1:1 fit template (top view, 150 x 100 mm)

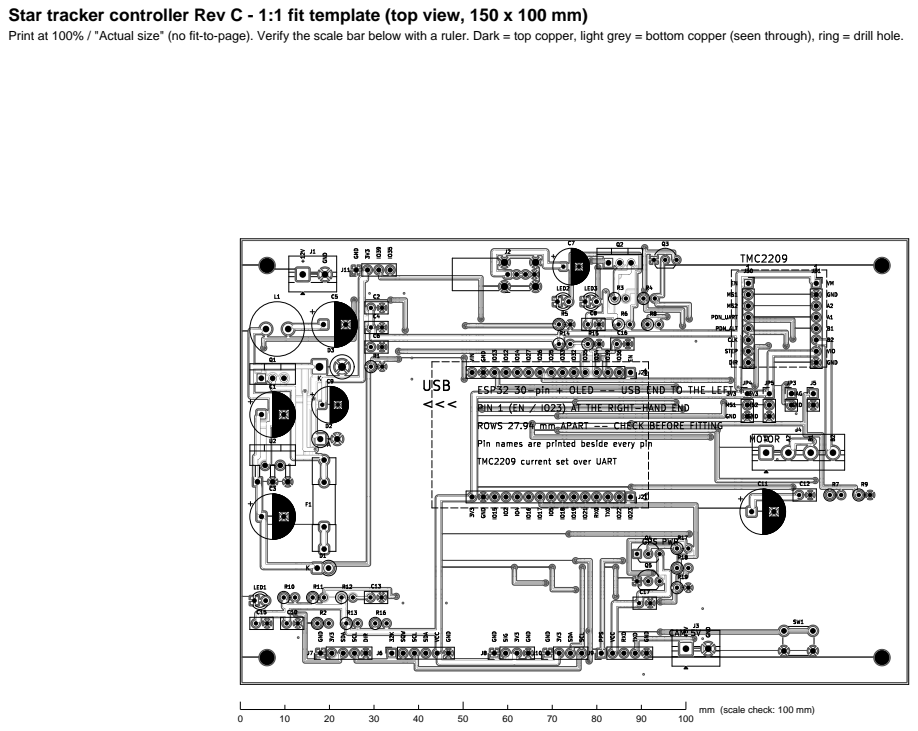
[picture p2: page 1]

Print at 100% / "Actual size" (no fit-to-page). Verify the scale bar below with a ruler. Dark = top copper, light grey = bottom copper (seen through), ring = drill hole.

mm (scale check: 100 mm)

## Inventory check - BOM (tick when in hand)

Qty | Refs | Value | Footprint | Note
1 | C1 | 470uF/25V | CP_Radial_D10.0mm_P5.00mm
1 | C11 | 100uF/25V LowESR | CP_Radial_D10.0mm_P5.00mm | VMOT bulk - MUST sit at the driver socket
10 | C10 C12 C13 C15 C16 C17 C2 C4 C6 C8 | 100nF | C_Disc_D5.0mm_W2.5mm_P2.50 mm
1 | C3 | 470uF/25V LowESR | CP_Radial_D10.0mm_P5.00mm
1 | C5 | 220uF/25V LowESR | CP_Radial_D10.0mm_P5.00mm
1 | C7 | 100uF/16V | CP_Radial_D8.0mm_P3.50mm
1 | C9 | 100uF/10V | CP_Radial_D8.0mm_P3.50mm
1 | D1 | 1N4744A 15V | D_DO-41_SOD81_P2.54mm_Vert ical_CathodeUp | Vgs clamp, cathode to source
1 | D2 | P6KE20CA | D_DO-15_P3.81mm_Vertical_Ano deUp
1 | D3 | 1N5822 | D_DO-201AD_P5.08mm_Vertical _CathodeUp | catch diode, cathode to SW node
1 | F1 | 3A | Fuseholder_Clip-5x20mm_Littelfu se_111_Inline_P20.00x5.00mm_D 1.05mm_Horizontal
1 | J1 | 12V IN | TerminalBlock_MaiXu_MX126-5.0 -02P_1x02_P5.00mm | 12-14.6V LiFePO4 in
1 | J10 | I2C EXP | PinHeader_1x04_P2.54mm_Vertic al | v2 compass
1 | J11 | SPARE IO | PinHeader_1x04_P2.54mm_Vertic al | the upper row's two free pins; both input-only
1 | J2 | CAM USB-A | USB_A_Wuerth_614004134726_ Horizontal | D+/D- shorted = dedicated charging port
1 | J20 | ESP32 L | PinSocket_1x15_P2.54mm_Vertic al
1 | J21 | ESP32 R | PinSocket_1x15_P2.54mm_Vertic al
1 | J3 | CAM 5V | TerminalBlock_MaiXu_MX126-5.0 -02P_1x02_P5.00mm
1 | J30 | TMC2209 L | PinSocket_1x08_P2.54mm_Vertic al
1 | J31 | TMC2209 R | PinSocket_1x08_P2.54mm_Vertic al
1 | J4 | MOTOR | TerminalBlock_MaiXu_MX126-5.0 -04P_1x04_P5.00mm | pins 1-2 one coil, 3-4 the other
1 | J5 | DIAG | PinHeader_1x02_P2.54mm_Vertic al
1 | J6 | DS3231 | PinSocket_1x06_P2.54mm_Vertic al | ZS-042 order: 32K SQW SCL SDA VCC GND
1 | J7 | AS5600 | PinHeader_1x05_P2.54mm_Vertic al | remote on the encoder bracket; pin5 = DIR->GND
1 | J8 | HOME | PinHeader_1x04_P2.54mm_Vertic al | optional opto flag; GND on BOTH end pins so the pour can always reach one of them
1 | J9 | GPS | PinHeader_1x05_P2.54mm_Vertic al | GY-NEO6MV2: pins 2-5 match its VCC/RX/TX/GND cable; PPS is a flying lead from the module's PPS LED pad
1 | JP3 | PDN ALT | PinHeader_1x02_P2.54mm_Vertic al
1 | JP4 | MS1 | PinHeader_1x03_P2.54mm_Vertic al
1 | JP5 | MS2 | PinHeader_1x03_P2.54mm_Vertic al
1 | L1 | 33uH 3A | L_Radial_D12.0mm_P5.00mm_Fa stron_11P
1 | LED1 | GRN 5V | LED_D3.0mm

## Inventory check - BOM (cont.)

Qty | Refs | Value | Footprint | Note
1 | LED2 | GRN CAM | LED_D3.0mm
1 | LED3 | RED ST | LED_D3.0mm
2 | Q1 Q2 | IRF4905 | TO-220-3_Vertical | reverse-polarity; drain to source of supply
2 | Q3 Q5 | 2N3904 | TO-92_Inline_Wide
1 | Q4 | 2N3906 | TO-92_Inline_Wide | PNP high-side switch; the module's own LDO makes 3.3V from this
7 | R1 R13 R16 R18 R3 R4 R9 | 10k | R_Axial_DIN0207_L6.3mm_D2.5 mm_P2.54mm_Vertical
2 | R10 R11 | 4.7k | R_Axial_DIN0207_L6.3mm_D2.5 mm_P2.54mm_Vertical | omit if the DS3231 module already has pull-ups (most do)
1 | R12 | 4.7k | R_Axial_DIN0207_L6.3mm_D2.5 mm_P2.54mm_Vertical | the wired-OR pull-up; always populate
1 | R14 | 100k 1% | R_Axial_DIN0207_L6.3mm_D2.5 mm_P2.54mm_Vertical
1 | R15 | 18k 1% | R_Axial_DIN0207_L6.3mm_D2.5 mm_P2.54mm_Vertical | 14.6V -> 2.23V at GPIO34
4 | R17 R2 R6 R7 | 1k | R_Axial_DIN0207_L6.3mm_D2.5 mm_P2.54mm_Vertical
2 | R19 R5 | 100k | R_Axial_DIN0207_L6.3mm_D2.5 mm_P2.54mm_Vertical | holds camera off while GPIO floats
1 | R8 | 330R | R_Axial_DIN0207_L6.3mm_D2.5 mm_P2.54mm_Vertical
1 | SW1 | CONFIG | SW_PUSH_6mm | also wakes from deep sleep via the GPIO4 wired-OR
1 | U2 | LM2596T-5.0 | TO-220-5_P3.4x3.7mm_StaggerO dd_Lead3.8mm_Vertical | TO-220-5; needs a clip heatsink above ~1.5A

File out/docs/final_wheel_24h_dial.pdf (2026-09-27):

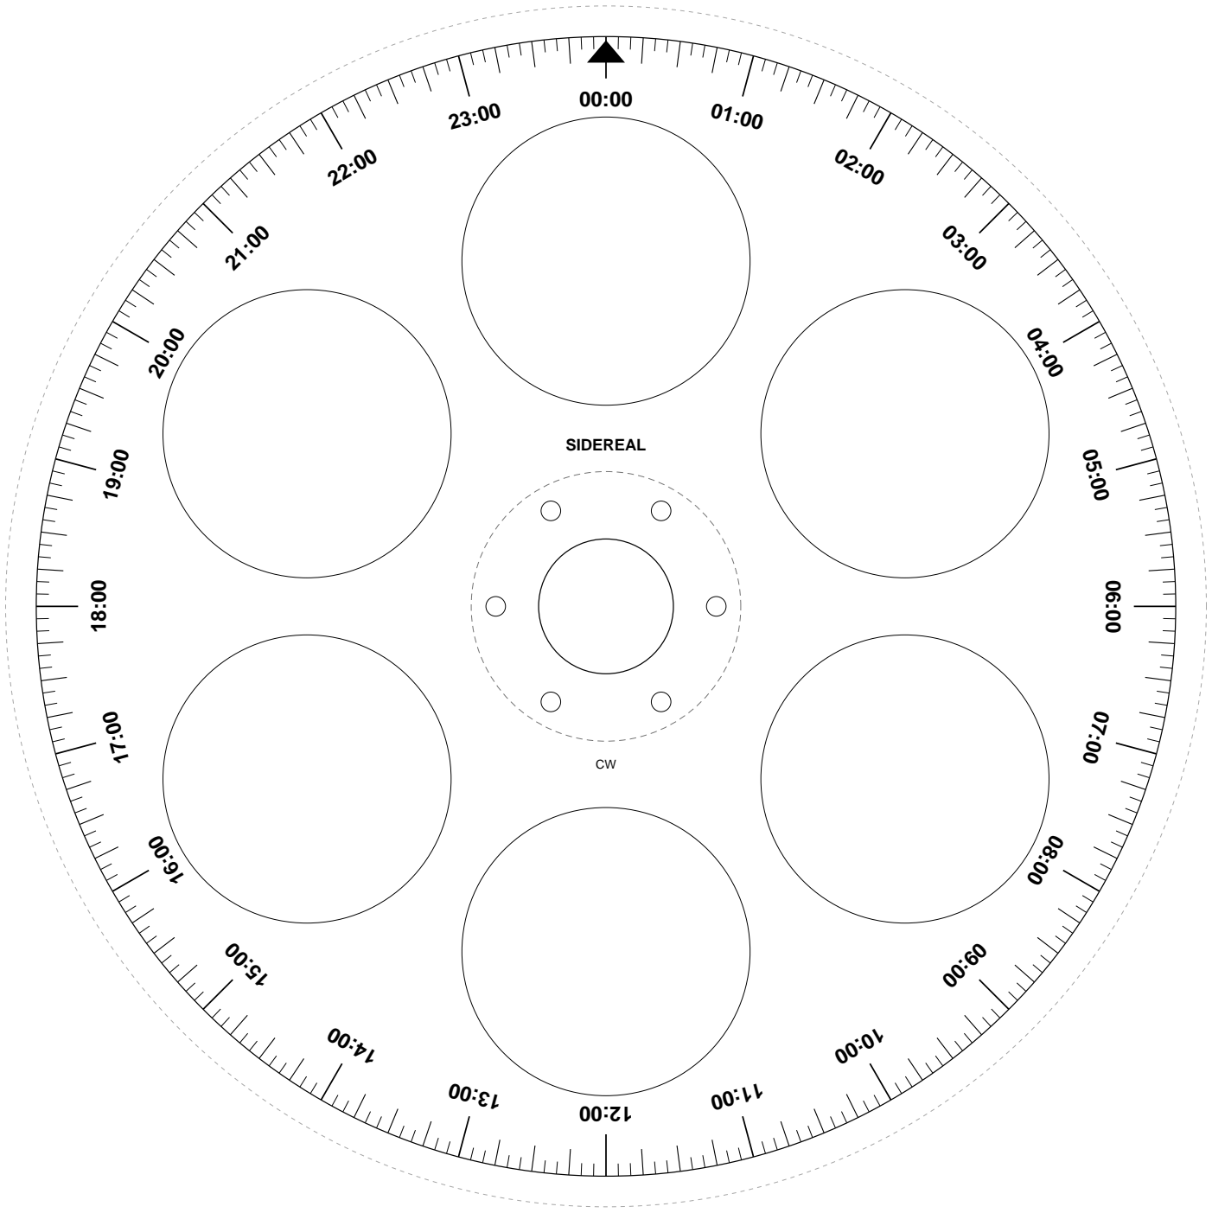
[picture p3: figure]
SIDEREAL

### 24 h SIDEREAL DIAL - final gear, 96 T module 2.0

Direction: HH increases CLOCKWISE viewed from above (printed side up).
One revolution = one sidereal day = 86164.1 s. 01:00 = one sidereal hour = 59 m 50.17 s of civil time - this reads hour angle, not wall clock.
1 tooth = 3.75 deg = 897.5 s = 14 m 57.5 s. 96 teeth over 24 h, so every 15-minute
tick is exactly one tooth pitch - use them to clock the dial.

Cut outs (build.ps1: bore=22, bc_holes=6, bc_r=18): outer 186.0 dia (0.5 inside the 187.0 root), 22 dia register bore, 6 x 3.2 dia bolts on r 18, 6 x 47.034 dia lightening holes on r 56.35 at 30 deg + i*60 deg. Those reach r 79.87, so all graduation sits in the solid band r 79.87 to 93.5. Outer dashed = tooth tips (196 dia); inner dashed 44 dia = clamp-hub footprint - trim there and skip the bolts.

PRINT AT 100% (page scaling off) - verify with the bar below.

0 | 100 mm
measure this: must be exactly 100 mm

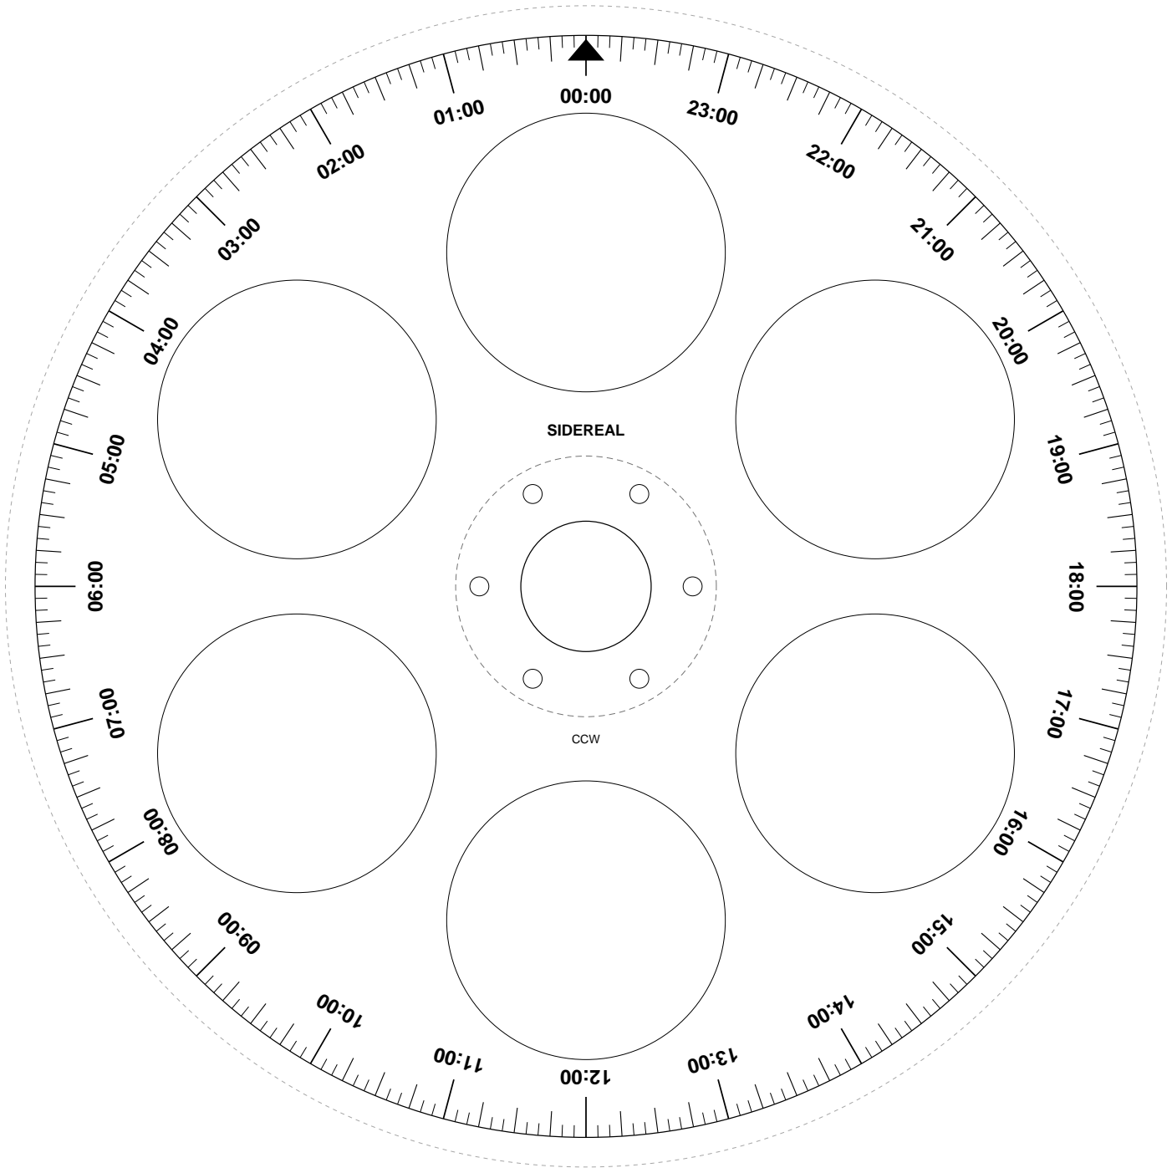
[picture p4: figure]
SIDEREAL; CCW

### 24 h SIDEREAL DIAL - final gear, 96 T module 2.0

Direction: HH increases COUNTER-CLOCKWISE viewed from above (printed side up). One revolution = one sidereal day = 86164.1 s. 01:00 = one sidereal hour = 59 m 50.17 s of civil time - this reads hour angle, not wall clock.
1 tooth = 3.75 deg = 897.5 s = 14 m 57.5 s. 96 teeth over 24 h, so every 15-minute
tick is exactly one tooth pitch - use them to clock the dial.

Cut outs (build.ps1: bore=22, bc_holes=6, bc_r=18): outer 186.0 dia (0.5 inside the 187.0 root), 22 dia register bore, 6 x 3.2 dia bolts on r 18, 6 x 47.034 dia lightening holes on r 56.35 at 30 deg + i*60 deg. Those reach r 79.87, so all graduation sits in the solid band r 79.87 to 93.5. Outer dashed = tooth tips (196 dia); inner dashed 44 dia = clamp-hub footprint - trim there and skip the bolts.

PRINT AT 100% (page scaling off) - verify with the bar below.

0 | 100 mm
measure this: must be exactly 100 mm

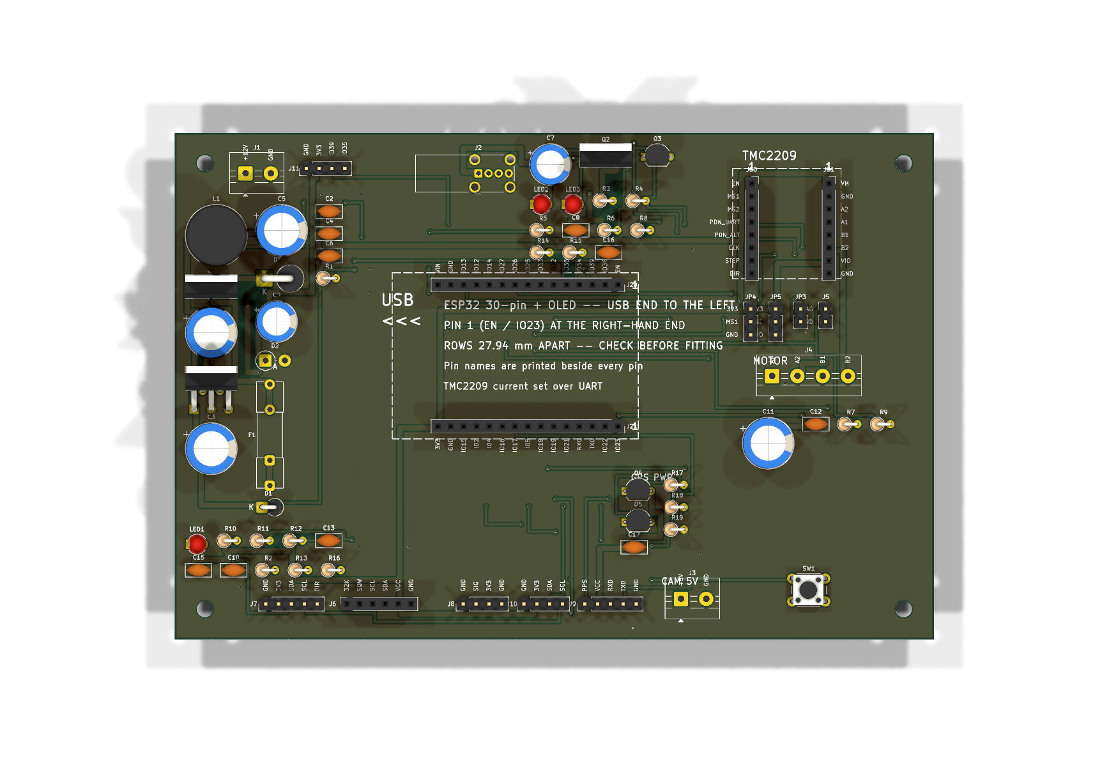
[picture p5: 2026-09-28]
hardware/board_top.png

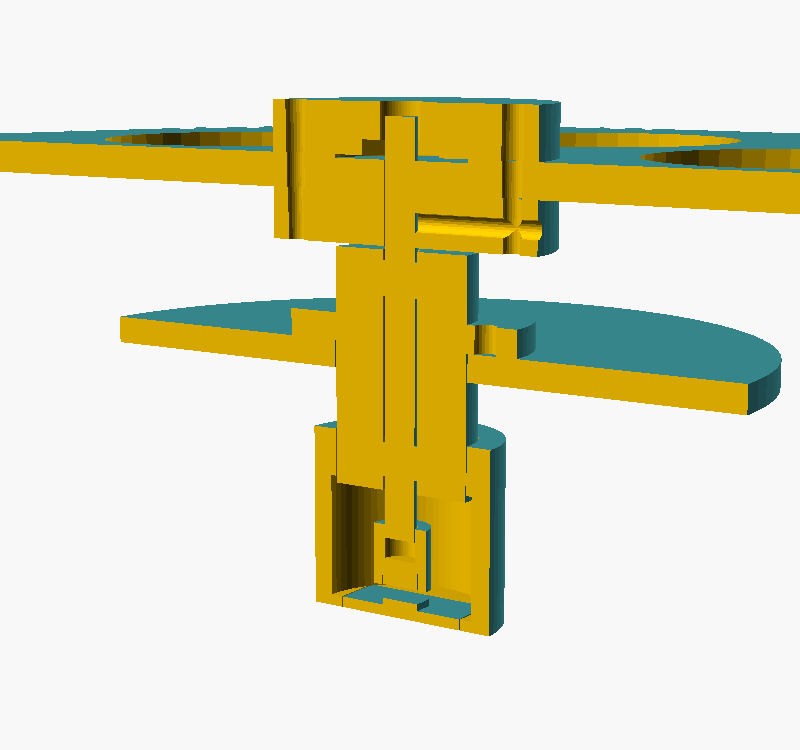
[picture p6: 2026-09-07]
out/docs/encoder_section.png

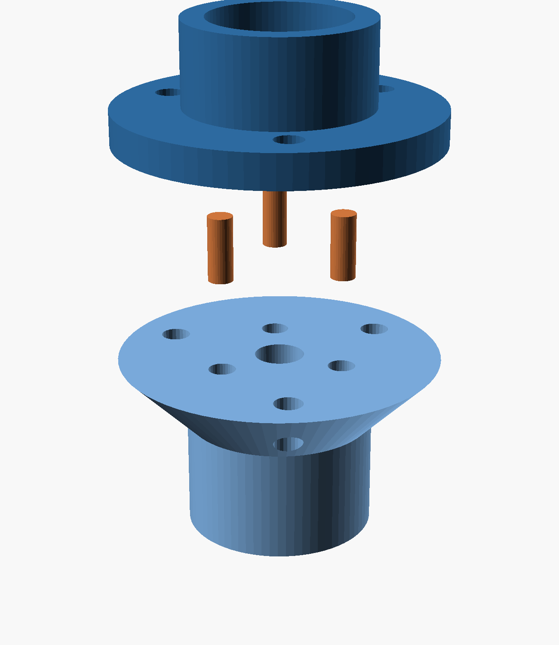
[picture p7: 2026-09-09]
out/docs/tower_split.png

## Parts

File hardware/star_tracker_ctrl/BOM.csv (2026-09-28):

Qty | Refs | Value | Footprint | Fitted | Note
1 | C1 | 470uF/25V | CP_Radial_D10.0mm_P5.00mm | yes
1 | C11 | 100uF/25V LowESR | CP_Radial_D10.0mm_P5.00mm | yes | VMOT bulk - MUST sit at the driver socket
10 | C10 C12 C13 C15 C16 C17 C2 C4 C6 C8 | 100nF | C_Disc_D5.0mm_W2.5mm_P2.50mm | yes
1 | C3 | 470uF/25V LowESR | CP_Radial_D10.0mm_P5.00mm | yes
1 | C5 | 220uF/25V LowESR | CP_Radial_D10.0mm_P5.00mm | yes
1 | C7 | 100uF/16V | CP_Radial_D8.0mm_P3.50mm | yes
1 | C9 | 100uF/10V | CP_Radial_D8.0mm_P3.50mm | yes
1 | D1 | 1N4744A 15V | D_DO-41_SOD81_P2.54mm_Vertical_CathodeUp | yes | Vgs clamp, cathode to source
1 | D2 | P6KE20CA | D_DO-15_P3.81mm_Vertical_AnodeUp | yes
1 | D3 | 1N5822 | D_DO-201AD_P5.08mm_Vertical_CathodeUp | yes | catch diode, cathode to SW node
1 | F1 | 3A | Fuseholder_Clip-5x20mm_Littelfuse_111_Inline_P20.00x5.00mm_D1.05mm_Horizontal | yes
1 | J1 | 12V IN | TerminalBlock_MaiXu_MX126-5.0-02P_1x02_P5.00mm | yes | 12-14.6V LiFePO4 in
1 | J10 | I2C EXP | PinHeader_1x04_P2.54mm_Vertical | yes | v2 compass
1 | J11 | SPARE IO | PinHeader_1x04_P2.54mm_Vertical | yes | the upper row's two free pins; both input-only
1 | J2 | CAM USB-A | USB_A_Wuerth_614004134726_Horizontal | yes | D+/D- shorted = dedicated charging port
1 | J20 | ESP32 L | PinSocket_1x15_P2.54mm_Vertical | yes
1 | J21 | ESP32 R | PinSocket_1x15_P2.54mm_Vertical | yes
1 | J3 | CAM 5V | TerminalBlock_MaiXu_MX126-5.0-02P_1x02_P5.00mm | yes
1 | J30 | TMC2209 L | PinSocket_1x08_P2.54mm_Vertical | yes
1 | J31 | TMC2209 R | PinSocket_1x08_P2.54mm_Vertical | yes
1 | J4 | MOTOR | TerminalBlock_MaiXu_MX126-5.0-04P_1x04_P5.00mm | yes | pins 1-2 one coil, 3-4 the other
1 | J5 | DIAG | PinHeader_1x02_P2.54mm_Vertical | yes
1 | J6 | DS3231 | PinSocket_1x06_P2.54mm_Vertical | yes | ZS-042 order: 32K SQW SCL SDA VCC GND
1 | J7 | AS5600 | PinHeader_1x05_P2.54mm_Vertical | yes | remote on the encoder bracket; pin5 = DIR->GND
1 | J8 | HOME | PinHeader_1x04_P2.54mm_Vertical | yes | optional opto flag; GND on BOTH end pins so the pour can always reach one of them
1 | J9 | GPS | PinHeader_1x05_P2.54mm_Vertical | yes | GY-NEO6MV2: pins 2-5 match its VCC/RX/TX/GND cable; PPS is a flying lead from the module's PPS LED pad
1 | JP3 | PDN ALT | PinHeader_1x02_P2.54mm_Vertical | yes
1 | JP4 | MS1 | PinHeader_1x03_P2.54mm_Vertical | yes
1 | JP5 | MS2 | PinHeader_1x03_P2.54mm_Vertical | yes
1 | L1 | 33uH 3A | L_Radial_D12.0mm_P5.00mm_Fastron_11P | yes
1 | LED1 | GRN 5V | LED_D3.0mm | yes
1 | LED2 | GRN CAM | LED_D3.0mm | yes
1 | LED3 | RED ST | LED_D3.0mm | yes
2 | Q1 Q2 | IRF4905 | TO-220-3_Vertical | yes | reverse-polarity; drain to source of supply
2 | Q3 Q5 | 2N3904 | TO-92_Inline_Wide | yes
1 | Q4 | 2N3906 | TO-92_Inline_Wide | yes | PNP high-side switch; the module's own LDO makes 3.3V from this
7 | R1 R13 R16 R18 R3 R4 R9 | 10k | R_Axial_DIN0207_L6.3mm_D2.5mm_P2.54mm_Vertical | yes
2 | R10 R11 | 4.7k | R_Axial_DIN0207_L6.3mm_D2.5mm_P2.54mm_Vertical | NO | omit if the DS3231 module already has pull-ups (most do)
1 | R12 | 4.7k | R_Axial_DIN0207_L6.3mm_D2.5mm_P2.54mm_Vertical | yes | the wired-OR pull-up; always populate
1 | R14 | 100k 1% | R_Axial_DIN0207_L6.3mm_D2.5mm_P2.54mm_Vertical | yes
1 | R15 | 18k 1% | R_Axial_DIN0207_L6.3mm_D2.5mm_P2.54mm_Vertical | yes | 14.6V -> 2.23V at GPIO34
4 | R17 R2 R6 R7 | 1k | R_Axial_DIN0207_L6.3mm_D2.5mm_P2.54mm_Vertical | yes
2 | R19 R5 | 100k | R_Axial_DIN0207_L6.3mm_D2.5mm_P2.54mm_Vertical | yes | holds camera off while GPIO floats
1 | R8 | 330R | R_Axial_DIN0207_L6.3mm_D2.5mm_P2.54mm_Vertical | yes
1 | SW1 | CONFIG | SW_PUSH_6mm | yes | also wakes from deep sleep via the GPIO4 wired-OR
1 | U2 | LM2596T-5.0 | TO-220-5_P3.4x3.7mm_StaggerOdd_Lead3.8mm_Vertical | yes | TO-220-5; needs a clip heatsink above ~1.5A

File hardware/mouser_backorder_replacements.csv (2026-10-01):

Mouser Part Number | Manufacturer Part Number | Manufacturer | Quantity | Description | Customer Part Number | Notes
647-UHE1E221MPD | UHE1E221MPD | Nichicon | 2 | Electrolytic 220 uF 25 V low impedance 105 C, 8 x 11.5 mm, 3.5 mm pitch | C5 C11 | Replaces backordered Panasonic EEU-FR1E221 (C5) and EEU-FR1E101 (C11). C11 goes from 100 uF to 220 uF: more VMOT bulk, fine. 3.5 mm leads into 5.0 mm pads: bend out. C11 must sit at the driver socket

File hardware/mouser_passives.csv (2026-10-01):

Mouser Part Number | Manufacturer Part Number | Manufacturer | Quantity | Description | Customer Part Number | Notes
 | C320C104K5R5TA | KEMET | 15 | Ceramic 100 nF 50 V X7R radial, 2.5 mm lead pitch | C2 C4 C6 C8 C10 C12 C13 C15 C16 C17 | 10 needed, 5 spare
 | EEU-FR1E471 | Panasonic | 2 | Electrolytic 470 uF 25 V low ESR, 10 mm dia, 5 mm pitch | C1 C3 | 10 mm / 5 mm pitch: matches footprint
 | EEU-FR1E221 | Panasonic | 1 | Electrolytic 220 uF 25 V low ESR, 8 mm dia | C5 | Leads are 3.5 mm pitch; footprint is 5.0 mm - bend leads out
 | EEU-FR1E101 | Panasonic | 1 | Electrolytic 100 uF 25 V low ESR, 6.3 mm dia | C11 | Leads are 2.5 mm pitch; footprint is 5.0 mm - bend out. VMOT bulk, must sit at driver socket
 | EEU-FR1C101 | Panasonic | 1 | Electrolytic 100 uF 16 V low ESR, 6.3 mm dia | C7 | Leads 2.5 mm; footprint 3.5 mm - bend out
 | EEU-FR1A101 | Panasonic | 1 | Electrolytic 100 uF 10 V low ESR, 6.3 mm dia | C9 | Leads 2.5 mm; footprint 3.5 mm - bend out
 | MFR-25FBF52-10K | YAGEO | 10 | Resistor 10 k 1/4 W 1% metal film | R1 R3 R4 R9 R13 R16 R18 | 7 needed
 | MFR-25FBF52-4K7 | YAGEO | 5 | Resistor 4.7 k 1/4 W 1% metal film | R12 (R10 R11 optional) | R12 required; R10/R11 only if the DS3231 module has no pull-ups
 | MFR-25FBF52-1K | YAGEO | 10 | Resistor 1 k 1/4 W 1% metal film | R2 R6 R7 R17 | 4 needed
 | MFR-25FBF52-100K | YAGEO | 10 | Resistor 100 k 1/4 W 1% metal film | R5 R19 R14 | 3 needed (R14 is spec'd 1%; 1% parts used for all)
 | MFR-25FBF52-18K | YAGEO | 5 | Resistor 18 k 1/4 W 1% metal film | R15 | 1 needed
 | MFR-25FBF52-330R | YAGEO | 5 | Resistor 330 ohm 1/4 W 1% metal film | R8 | 1 needed
 | 19R333C | Murata Power Solutions | 1 | Radial inductor 33 uH 10% 3.7 A 32 mOhm, 12 mm dia x 23 mm, 6 mm lead pitch | L1 | Datasheet-verified (KMP_1900RC_C01). Leads 6.0 mm pitch vs 5.0 mm footprint: squeeze 1 mm. Body 12 mm matches

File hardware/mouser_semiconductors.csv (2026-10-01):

Mouser Part Number | Manufacturer Part Number | Manufacturer | Quantity | Description | Customer Part Number | Notes
926-LM2596T-5.0/NOPB | LM2596T-5.0/NOPB | Texas Instruments | 2 | 5 V 3 A buck regulator, TO-220-5 | U2 | Clip heatsink above ~1.5 A. 1 spare
942-IRF4905PBF | IRF4905PBF | Infineon | 3 | P-channel MOSFET 55 V 74 A, TO-220 | Q1 Q2 | 2 needed, 1 spare
 | 2N3904BU | onsemi | 5 | NPN transistor, TO-92 | Q3 Q5 | 2 needed
 | 2N3906BU | onsemi | 3 | PNP transistor, TO-92 | Q4 | 1 needed
512-1N4744A | 1N4744A | onsemi | 3 | Zener 15 V 1 W, DO-41 | D1 | 1 needed
576-P6KE20CA | P6KE20CA | Littelfuse | 2 | Bidirectional TVS 600 W 17.1 V standoff, DO-15 | D2 | 1 needed
 | 1N5822-E3/54 | Vishay | 3 | Schottky 40 V 3 A, DO-201AD | D3 | onsemi 1N5822 is obsolete at Mouser; Vishay equivalent
 | WP710A10GD | Kingbright | 3 | LED 3 mm green | LED1 LED2 | 2 needed
 | WP710A10ID | Kingbright | 2 | LED 3 mm red | LED3 | 1 needed

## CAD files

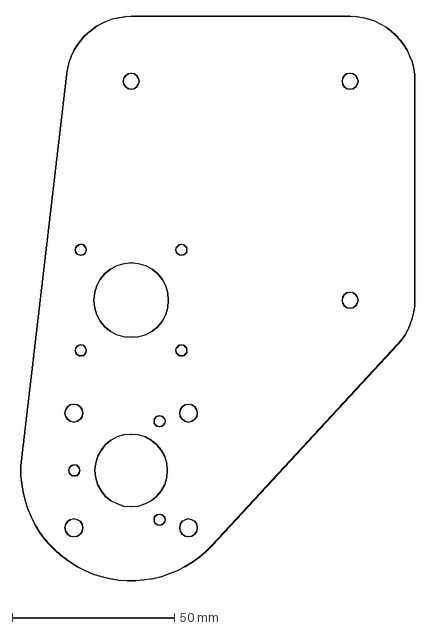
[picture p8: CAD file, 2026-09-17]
out/docs/baseplate_cut.dxf
123.0 x 177.0 mm

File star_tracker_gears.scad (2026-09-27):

// =====================================================================
//  star_tracker_gears.scad
//  Parametric involute gear train for a sidereal-rate camera tracker.
//
//  Self-contained -- no libraries. Needs OpenSCAD 2021.01+ (offset()).
//
//  TWO BUILDS share stages 1-3 (15/120 module 1.0, 8:1 each = 512:1):
//
//  (A) all printed      final 15/135 module 1.0  ->  4608:1
//        200-step motor @ 1/16  ->  14,745,600 usteps/sidereal day
//        5843.38 us/step, motor 3.209 rpm, 0.088 arcsec/ustep
//        parts: 3 x "stage", 1 x "output", 1 x "pinion"
//
//  (B) laser final      final 24/96  module 2.0  ->  2048:1
//        200-step motor @ 1/32  ->  13,107,200 usteps/sidereal day
//        6573.80 us/step, motor 1.426 rpm, 0.099 arcsec/ustep
//        parts: 2 x "stage", 1 x "finalstage", 1 x "pinion",
//               + "lasercut" SVG sent out for cutting
//
//  (B) exists because module-1 tooth tips are 0.69 mm -- too fine for a
//  laser. Module 2.0 gives 1.43 mm tips AND triples the final pinion
//  radius, which is what actually sets short-exposure trailing:
//      excursion over t  =  (e / r_pinion) * 2*pi*t / 86164
// =====================================================================

/* [What to render] */
// train = layout check, plate = ready to slice, test_pair = check the mesh
part = "test_pair";  // [train, plate, stage, output, pinion, testwheel, testplate, fitgauge, boregauge, spacers, assembly, encoder, tower, hublower, hubupper, magnetcap, as5600bracket, bearinggauge, baseplate, baseplatecut, towerlower, towerupper, towerdowels, towersplit, finalwheel, finalstage, finalpinion, laserwheel, lasercut, dxf, test_pair]

/* [Gear cutting] */
mod_      = 1.0;    // transverse module, mm
pa        = 20;     // pressure angle, deg
backlash  = 0.25;   // total backlash per mesh, mm (0.15 tight .. 0.35 loose)
clear_    = 0.25;   // root clearance, x module
fillet    = 0.35;   // root fillet radius, mm (0 = off)
helix     = 0;      // helix angle, deg. 0 = spur. Try 15 for quiet running.
flank_pts = 14;     // involute sample points per flank

/* [Tooth counts] */
zp = 15;            // pinion, every stage
zw = 120;           // wheel, stages 1-3
zf = 135;           // final wheel

/* [Sizes] */
fw_wheel  = 5;      // wheel face width
fw_pinion = 7;      // pinion face width -- 2 mm MORE than fw_wheel on purpose,
                    // so consecutive wheels can be axially separated by z_gap
                    // while the pinion still covers the full wheel face
z_gap     = 1.5;    // axial gap between consecutive wheels in the stack
hub_d     = 12;     // hub boss diameter
lighten   = true;   // lightening holes in the big wheels

/* [Centre mount] */
// How the part attaches to its shaft.
//   round    - plain through hole
//   dshaft   - round hole with a flat, for a NEMA17 D-cut shaft
//   hex      - hex socket, traps an M5 nut so an M5 bolt becomes the shaft
//   bearing  - through hole + press-fit pocket for a ball bearing
//   thread   - undersize hole to thread-form a bolt straight into plastic
mount_type = "round";  // [round, dshaft, hex, bearing, thread]
out_mount  = "round";  // [round, dshaft, hex, bearing, thread] - output wheel only

bore    = 5.2;   // 5 mm shaft, printed loose. M5 bolt = 5.3
d_flat  = 2.1;   // axis to the D flat. NEMA17 is 2.0 + 0.1 clearance
hex_af  = 8.2;   // across flats. M5 nut = 8.0 + 0.2
brg_od  = 16.0;  // bearing outer race. 625ZZ = 16, 608ZZ = 22
brg_id  = 5.0;   // bearing bore (only used to size the shaft clearance)
brg_w   = 5.0;   // bearing width. 625ZZ = 5, 608ZZ = 7
thread_d = 5.5;  // 1/4"-20 formed into plastic. M5 = 4.6, M6 = 5.5

/* [Laser-cut final stage] */
// Coarse module so the tooth tips survive a laser. Short-exposure trailing
// scales as 1/r_pinion, so the big final pinion is the real win here --
// 24T at module 2 has r=24 mm against the old 15T at module 1's r=7.5 mm.
mod_f    = 2.0;   // final stage module
zpf      = 24;    // final pinion teeth  (PRINTED, sits on shaft 3)
zwf      = 96;    // final wheel teeth   (LASER CUT)  -> 4:1
lw_bore  = 20;    // central clearance hole in the laser wheel
lw_bolts = 6;     // clamp bolts holding it to the printed carrier
lw_bc_r  = 35;    // clamp bolt circle radius
lw_bc_d  = 3.2;   // M3 clearance

/* [Backlash test jig] */
tp_zw       = 30;    // wheel teeth used on the test plate
tp_post_d   = 4.70;  // SHAFT POST DIAMETER -- measured on the fit gauge
                     // 4.70 post <-> 5.20 nominal bore = 0.50 mm total
                     // hole-shrink + post-growth on this printer/filament.
fg_d0       = 4.70;  // fit gauge: smallest stub
fg_step     = 0.10;  // fit gauge: step
fg_n        = 7;     // fit gauge: number of stubs
bg_d0       = 5.00;  // bore gauge: smallest hole
bg_step     = 0.10;  // bore gauge: step
bg_n        = 7;     // bore gauge: number of holes
bg_t        = 6;     // bore gauge thickness (~ a gear face width)
bpg_d0      = 16.0;  // bearing gauge: smallest pocket (625ZZ is 16.0 nominal)
bpg_step    = 0.1;
bpg_n       = 8;
bpg_t       = 8;     // bearing gauge bar thickness
tp_plate_t  = 4;     // plate thickness
tp_collar_d = 11;    // collar the gear rides on, clear of the plate face
tp_collar_h = 1.2;
tp_screw_d  = 2.7;   // M3 thread-forming, retains the keeper washer

/* [Shaft spacers] */
// Each gear is set to its Z height by a spacer stack under it. The spacer OD
// is the TIGHTEST fit in the whole gearbox: a spacer on shaft 2 shares a Z
// band with shaft 1's 120T wheel, 67.5 mm away with a 61 mm tip radius, so
// its radius cannot exceed 6.5 mm. 13 mm OD is the hard wall; 10 mm leaves
// 1.5 mm of air. Same story for shaft 3 against shaft 2's wheel.
sp_od  = 10;   // spacer outside diameter -- HARD MAX 13
sp_clr = 2;    // running clearance between baseplate and the lowest gear
explode = 0;   // assembly view only: lift every gear off its spacer, mm

/* [Output shaft and AS5600 encoder] */
// The output is the ONE shaft that rotates: the magnet must sit on the axis
// and turn with the wheel, and the camera load wants real bearings anyway.
os_shaft_d = 5.0;    // ground shaft, not a nail
os_brg_od  = 16;     // 625ZZ outer race
os_brg_w   = 5;      // 625ZZ width
os_tower_od = 22;    // bearing tower OD -- also the sensor bracket's register
os_hub_od  = 44;     // clamp hubs; must exceed 2*bc_r so the bolts land in meat
os_reg_d   = 22;     // register the wheel is located on
os_mag_d   = 6;      // diametric magnet
os_mag_h   = 2.5;
os_flange_d = 44;    // tower flange. Sized by the bolt circle below, then
                     // checked against shaft 1's wheel: 85.5 - 61 - 22 = 2.5 mm
os_flange_bc = 35;   // flange bolt circle dia. At Ø28 the web between the
                     // plate's Ø22.4 spigot bore and each M3 was only 1.10 mm
                     // -- under the min-feature rule for 4 mm aluminium.
                     // Ø35 gives 4.60 mm.
os_brg_fit = 0.5;    // bearing pocket allowance -- SET THIS FROM THE BEARING GAUGE
os_cut     = false;  // cut the assembly in half for a section view (needs --render)

/* [Split bearing tower] */
// The one-piece tower will not print, so it is two halves that CLAMP THE
// BASEPLATE between them. Rev A split at z = 0 with a 45 deg cone under the
// flange, but that cone sat inside the 4.3 mm plate (32-44 mm across where the
// plate hole is 22.4) and the flange could never seat.
//   upper half: flange on the plate top + tube, z 0 .. 14
//   lower half: clamp disc against the plate underside + tube, z -21 .. -bp_t
// Nothing of either half is inside the plate hole; the dowels bridge that gap.
// Both halves print with their plate-facing face on the bed, and each one only
// gets narrower going up the print, so neither has an overhang. The lower
// disc's underside is also the AS5600 bracket's axial stop.
os_disc_d   = 41;    // lower clamp disc. Max ~41: the wedge adapter's M5s sit
                     // at r 25 and need adapter material between them and it
os_disc_t   = 6.5;   // thick enough for M3x14 to thread-form 5.7 mm into it
os_pin_n    = 3;     // alignment dowels
os_pin_r    = 8;     // dowel circle radius (clear of the bore and the M3s)
os_pin_d    = 3.2;   // socket dia
os_pin_len  = 4.0;   // socket depth into EACH half; the dowel also spans bp_t
os_exp     = 0;      // exploded view: axial separation between parts, mm
os_shaft_len = 55;   // ground shaft cut to this. Bottom bottoms in the magnet
                     // cap at z -33; top at z 22 clears the hub grub (z 17.5)
                     // and stays under the camera nut (z 26.5)
os_washer_t = 1.0;   // printed washer on the upper bearing's INNER race, so the
os_washer_od = 7.2;  // turning hub never touches the tower rim or outer race
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

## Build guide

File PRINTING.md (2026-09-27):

# Printing guide

What to print, in what order, and with what settings. Every file named here is
generated into `out/` by `.\build.ps1` — see [README.md](README.md) for the
design and [DESIGN_NOTES.md](DESIGN_NOTES.md) for why it is the way it is.

All-printed build, module-2 final stage. **2048:1**, `USTEPS_PER_REV = 13,107,200`
at 1/32 microstepping.

**Every STL here is cut at `bore = 5.2` nominal.** On this printer that lands
near 4.9-5.0 mm actual, which suits a 20d common nail (4.88 mm) better than it
suits true 5.00 mm ground stock. See *Shafts* below.

## The gear train — 5 pieces from 4 files

| File | Qty | What |
|---|---|---|
| `pinion.stl` | 1 | 15T motor pinion, **D-shaft bore 5.45** for the NEMA17's 5.00 mm ground shaft |
| `stage.stl` | **2** | 120T + 15T compound, 8:1 — shafts 1 and 2 |
| `final_stage_gear.stl` | 1 | 120T module-1 wheel + **24T module-2** pinion, one piece — shaft 3 |
| `final_wheel_96T_m2_PRINTED.stl` | 1 | 96T module-2 output wheel, 196 mm OD, 4:1. **Ø22 bore, 6 bolts at r=18** — it locates on the hub register, not on its own bore |

Note `stage.stl` is **2**, not 3 — the third compound is `final_stage_gear.stl`,
which carries the coarse module-2 pinion.

## Baseplate — cut, not printed

121.5 x 174 mm, too big for either bed and wanting stiffness rather than
strength, so it is a cut part.

**6061 aluminium, 4.3 mm as ordered** (nearest stock to the 4.0 mm designed).
157 cm2, ~182 g.

The extra 0.3 mm changes nothing dimensional: **every gear height is referenced
from the plate's top face**, so thickness lives entirely below the datum. It
buys 24% more bending stiffness (t^3) for 13 g. Two fastener consequences:

- **Tower:** flange 4 + plate 4.3 = 8.3 mm of grip, then **M3x14** thread-forms
  5.7 mm into the lower tower half's clamp disc. No nuts.
- **Motor: countersink the four holes and use M3x8 flat head (ISO 10642).**
  The S1 120T wheel runs 2.0 mm above the plate and passes over the two motor
  screws on its side, 54 mm from S1, so a 3 mm socket-cap head hits it. A
  button head (1.65 mm) clears by 0.35 mm if you would rather not countersink.
  M3x10 is too long: 5.7 mm of thread past the plate bottoms out in the
  NEMA17's ~4.5 mm holes before it clamps. The rule is **thread = length -
  4.3, and it must be shorter than the motor's holes** -- gauge them with a
  drill bit.
- **Wedge:** the M5 hole nearest S1 is also under the S1 wheel. Nothing above
  the plate there may stand more than 1.5 mm proud: countersink it, or leave
  that bolt out.

**Watch for one thing on the DFM review:** the M3 holes are Ø3.4, which is
0.79 x material thickness. The usual laser rule is minimum hole diameter >= 1 x
thickness. This was already true at 4.0 mm (0.85x) and is slightly worse at
4.3. If the quote priced without comment it passed their check; if it comes
back flagged, this is why, and the fix is to open those four motor holes and
three flange holes to Ø4.5 and use washers. 3 mm works if the wedge
sits close to the output shaft; below 3 mm the bearing-tower flange will dimple
it.

**Send `out/docs/baseplate_cut.dxf`** — SendCutSend wants DXF. It carries the
outline as **4 ARC + 4 LINE** (the hull of circles decomposes exactly into arcs
joined by their common tangents) and every hole as a true **CIRCLE**: 16 of
them, 24 entities total.

Do **not** export DXF from OpenSCAD. Its writer emits the whole profile as
loose line segments — **708** of them for this part, with every hole a faceted
polygon and not one CIRCLE. Services reject or mis-cut that.

`baseplate_cut.svg` is the same geometry (17 closed contours) if a vendor
prefers SVG. R12 DXF has no reliable units record, so **state mm on upload**;
the file measures 121.50 x 174.00 mm, which is the giveaway if anything reads
it as inches.

**DFM note:** the tower flange bolt circle is Ø35, not Ø28. At Ø28 the web
between the plate's Ø22.4 spigot bore and each M3 was only **1.10 mm** — under
the min-feature rule for 4 mm aluminium. Ø35 gives 4.60 mm, and the tower
flange grew to Ø44 to suit, which still clears shaft 1's wheel by 2.5 mm.
`os_flange_bc` and `bp_tower_bc` must stay equal.

The outline is a hull of lobes at the five shaft centres, not a slab under the
whole gear footprint: **the wheels overhang the plate on purpose**, so the plate
only carries the shafts and the motor. That is what takes it from ~740 g to
170 g.

Holes, all in the SVG and on the 1:1 template:

| Where | What |
|---|---|
| S0 | dia 23 NEMA17 pilot boss + 4 x M3 on a 31 mm square |
| S1-S3 | dia 4.9, light press for 20d nails driven up from underneath |
| S4 | dia 22.4 tower clearance + 3 x M3 on dia 35 |
| S4 | **4 x M5 on dia 50 — the wedge/tripod interface** |

The wedge bolts are centred on the **output axis**, not the plate centroid. The
camera moment is reacted where it is generated, which is the shortest load path
and the reason the plate can be this thin.

`out/docs/baseplate_template.pdf` is the same thing at 1:1 on US Letter with
both scale bars — use it to check the SVG before ordering, or as a drilling
template on stock you cut yourself.

**One consequence:** shaft 0 has no usable spacer. Its hole is dia 23 for the
motor boss, so the 2 mm spacer would fall through. The motor pinion's height is
set by its grub screw on the NEMA17 shaft instead. Spacers 1-4 are unaffected.

## Output shaft and AS5600 encoder

The output is the one shaft that rotates: the encoder magnet has to sit on the
axis and turn with the wheel, and the camera load wants real bearings anyway.

| File | Qty | What |
|---|---|---|
| `output_tower_LOWER.stl` | 1 | clamp disc under the plate, spigot tube, lower 625ZZ pocket |
| `output_tower_UPPER.stl` | 1 | flange on the plate top, upper 625ZZ pocket |
| `output_tower_DOWELS.stl` | 1 | three Ø2.9 x 11.9 alignment dowels (they cross the plate) |
| `output_hub_lower.stl` | 1 | clamps the shaft, Ø22 register the wheel locates on |
| `hub_washer.stl` | 1 | Ø7.2 x 1.0, sits on the upper bearing's inner race |
| `output_hub_upper.stl` | 1 | camera platform, 10 mm thick, pocket for a full 1/4"-20 nut |
| `magnet_cap.stl` | 1 | presses on the shaft end, 1.5 mm floor under the magnet |
| `as5600_bracket.stl` | 1 | slides up the tower spigot until it stops on the clamp disc; PCB screws to its underside |

Also needed: a **5 mm ground shaft cut to 55 mm** (not a nail — this one runs
in bearings and carries the encoder), 2 x 625ZZ, a **diametrically** magnetised
6 x 2.5 magnet, a standard 1/4"-20 hex nut (7/16" AF x 7/32"), and an AS5600
breakout.

**The shaft is 55 mm, not the 65 you buy.** Its bottom end bottoms in the
magnet cap at z -33; its top end at z 22 is above the hub grub screw (z 17.5)
and below the camera nut (z 26.5). Rev A drew it to z 34, straight through
the nut.

**Verified geometry:** hubs Ø44, cap Ø9 x 9, bracket Ø30 x 29.2. Bearing
centres 30 mm apart. **Magnet face to sensor die = 2.0 mm**, inside the
AS5600's 0.5-3.0 mm window, and now set by the parts: the bracket stops on the
disc.

### The tower is two halves that clamp the plate

One piece will not print: bottom-up its first layer is a 166 mm2 ring under a
35 mm part, and top-down the flange becomes an 8 mm 90 degree ledge.

Rev A split it at z = 0 with a 45 degree cone under the flange. **That cone sat
inside the plate:** 32-44 mm across where it passed through a 22.4 mm hole, so
the flange could never seat, and a tower sitting high lifts the 96T wheel off
its pinion.

Rev B puts the plate between the halves:

- **Upper half**, z 0 to 14: Ø44 flange on the plate's top face, tube up to the
  upper bearing.
- **Lower half**, z -21 to -4.3: Ø41 x 6.5 clamp disc against the plate's
  underside, tube down to the lower bearing and the bracket spigot.
- **Nothing is inside the plate hole.** Three Ø3.2 sockets, 4 mm into each
  half, carry dowels that span both sockets and the plate (11.9 mm).
- **3 x M3x14 from the top:** clearance through the flange and plate, then
  thread-forming 5.7 mm into the disc. The plate is clamped, and it becomes
  part of the tower.

The disc is Ø41 rather than Ø44 for the wedge adapter: its M5s are at r 25 and
need adapter material between them and the disc. **The adapter needs a Ø42 x 7
relief** for the disc, and a through-hole of at least 32 mm for the bracket.

No glue: the halves never touch each other. Dry-fit the dowels, sandwich the
plate, screw down.

### Print orientation matters on four of these
- **Tower halves — the plate-facing face down**, both of them. Flange face for
  the upper half, disc top face for the lower. Each half then only gets
  narrower going up the print, so neither needs supports.
- **Magnet cap — magnet pocket down.** Small part: print three or four at once
  or the layers never cool.
- **Bracket — floor down.** Everything above it is open upward.
- **Hub washer** — batch it with the magnet caps for the same reason.

Both hubs print flat-face-down with no overhangs.

### Hub washer

The upper bearing's top face is flush with the tower top, and so was the lower
hub's underside, so the turning hub dragged on the fixed tower rim and the
bearing's outer race. The washer bears on the **inner race only**. Ø7.2 is
meant to stay inside the shield; hold it against a bearing and check that it
does before relying on it. Inner race, washer, hub and shaft all turn together, so a
printed washer never wears. The lower hub is 1 mm shorter to match, which keeps
the 96T wheel at z 21.5 inside its 24T pinion. A steel 5 x 7 x 1 shim works
too; a Ø10 washer does not, it rubs the shield.

### Stage gears have no grub-screw holes

Rev A cut a grub hole in `stage.stl` and `final_stage_gear.stl`. Those gears
turn on nails pressed into the plate, so a grub screw there locks the train.
Only the motor pinion and the lower hub take grub screws. If you printed Rev A
gears, leave the holes empty.

### Concentricity comes from the parts, not from you

The AS5600 needs the magnet centred over the die within ~0.25 mm. The bracket
therefore registers on the **same tower boss that holds the lower bearing**, so
concentricity is built in rather than dialled in. Do not substitute slotted
holes and eyeballing.

Firmware setup aid: read the AS5600's `AGC` and `MAGNITUDE` registers over I2C.
They tell you "too far / too close" as a number, so the air gap is measured
rather than guessed.

## Shaft spacers

`SPACERS_shaft_0-4.stl` — five spacers, left to right = shafts 0,1,2,3,4:

| Shaft | Height | Sets |
|---|---|---|
| 0 | 2.0 mm | motor pinion off the plate |
| 1 | 2.0 mm | 120T wheel off the plate |
| 2 | 8.5 mm | one stage up |
| 3 | 15.0 mm | two stages up |
| 4 | 21.5 mm | output wheel |

Heights are computed as `sp_clr + (i-1) x (fw_wheel + z_gap)`, so if you switch
to the slim 3 mm-face stack they recompute to 2, 2, 6, 10, 14 automatically.

**The spacer OD is the tightest fit in the whole gearbox.** A spacer on shaft 2
shares a Z band with shaft 1's 120T wheel, 67.5 mm away with a 61 mm tip radius:

```
shaft only (r 2.5)   67.5 - 61 - 2.5 = 4.0 mm clear
10 mm spacer (r 5)   67.5 - 61 - 5.0 = 1.5 mm clear
13 mm spacer         67.5 - 61 - 6.5 = 0.0 mm  <-- hard wall
```

Same story for shaft 3 against shaft 2's wheel. Shafts 0, 1 and 4 are
unconstrained — their spacers never share a Z band with a neighbouring wheel.
**Never fit a stock 5 mm shaft collar (12-16 mm OD) at shafts 2 or 3.**

Printed on end so the end faces are first/last layers and come out flat; the
bore is chamfered both ends so first-layer squish cannot cock them over.

Note the 2 mm `sp_clr` under the lowest gear — earlier layouts had the shaft-1
wheel sitting at z = 0, i.e. rubbing on the baseplate.

## Shafts

Five shafts, 15–32 mm of working length each (see the spacer heights above,
plus the gear stack). They are FIXED — the gears turn on them.

**20d bright common nails, 0.192 in = 4.88 mm.** Closest standard nail to 5 mm,
and a better match to the as-printed 5.2 bore than true 5.00 mm stock would be.

Shafts 1-4 only. **Shaft 0 is the motor's own 5.00 mm ground shaft**, so
`pinion.stl` is cut differently from the rest:

| File | Bore | Flat |
|---|---|---|
| `pinion_bore5.30.stl` | 5.30 | 2.150 |
| **`pinion.stl`** | **5.45** | **2.225** |
| `pinion_bore5.60.stl` | 5.60 | 2.300 |

All three are `mount_type = "dshaft"` — the hole is a circle clipped by a flat,
matching the NEMA17 D-cut, so the pinion cannot slip however the grub screw
behaves. The flat tracks the bore at `2.0 + (bore - 5.0)/2`, because a printed
flat needs the same radial compensation the bore gets.

5.45 is the estimate from the 0.50 mm offset the fit gauge measured. Print all
three next to `stage.stl` — you need that gear anyway, and batching also fixes
the minimum-layer-time problem that makes a lone pinion droop. Try each on the
motor shaft and keep the tightest one that slides on without force.

| Nail | Diameter | Verdict |
|---|---|---|
| 16d common | 0.162 in / 4.11 mm | ~0.8 mm of slop — this is why the first test mount felt loose |
| **20d common** | **0.192 in / 4.88 mm** | **use this** |
| 30d common | 0.207 in / 5.26 mm | too fat for a 5.2 nominal bore that printed under |

Specify **common** and **bright**. Box nails and sinkers run a gauge thinner for
the same penny size; galvanised nails have a lumpy zinc coating and are useless
as a bearing surface.

- **Roll-test every nail** on glass or a saw table and keep the five straightest.
  A bent shaft is eccentricity, and on shaft 3 that is the dominant tracking
  error — see the error budget in [README.md](README.md).
- Cut the point off and square the end. A 20d is 4 in long; you need ~30 mm.
- Drive them **up from underneath** so the head (~8.9 mm, well under the 13 mm
  limit) seats against the underside of the baseplate. Positive location, and
  the head sits below everything so it fouls nothing.

**Upgrade path:** shaft 3 carries the final pinion and sets short-exposure
trailing. If measurement says it is the limit, replace that one with ground
stock — a 5 mm drill blank, or the shank of a cheap 5 mm HSS drill bit, both
ground to h8. That will need the bore opened, either by reaming or by
re-rendering `final_stage_gear.stl` at a larger `bore`.

## Calibration — print these FIRST

Three gauges, all in `out/_scratch/`, all sub-15-minute prints. Each exists
because a dimension on this printer cannot be predicted, only measured.

| File | Why |
|---|---|
| `BOREGAUGE_hole_diameters.stl` | Stepped holes 5.0–5.6. Push a real 5 mm shaft through (a 5 mm drill shank is a precise gauge pin); the smallest hole that turns freely is what `bore` should be. **Needed for the motor pinion** — a NEMA 17 shaft is ground 5.00 mm and will not enter a bore that printed at 4.9. Push the actual motor shaft through the gauge and re-render `pinion.stl` at that bore. The other four gears run on 4.88 mm nails and are fine as cut. |
| `FITGAUGE_post_diameters.stl` | Stepped posts. Already run → **4.70** on this printer. Re-run with `-D fg_d0=` if you change filament. |
| `TESTPLATE_15T_30T.stl` | Backlash jig, posts at 22.5 mm centres, cut for the measured 4.70. |
| `TEST_wheel_30T.stl` | The 30T mate for the test plate. Pairs with `pinion.stl`. |
| `BEARINGGAUGE_pockets.stl` | **Print before the bearing tower.** Eight stepped pockets, 16.0 to 16.7. Printed holes come out undersize, so a nominal 16.0 pocket will not take a 16.0 bearing. Push a real 625ZZ into each; use the smallest that seats with firm thumb pressure — not one you have to hammer, and not one it drops into. Then set `os_brg_fit` (or `$BrgFit` in `build.ps1`) to that value minus 16.0. |

## Laser option

`final_wheel_96T_m2_laser.svg` — the same 96T wheel as a flat profile for
SendCutSend, cut at `backlash = 0.35`, 60 points per flank. Only needed if you
decide to have the final wheel cut from .063″ aluminium instead of printing it.
Ignore it otherwise.

## `out/docs/`

| File | What |
|---|---|
| `assembly.png` | Assembled 3/4 view — the whole gearbox on its baseplate |
| `assembly_exploded.png` | Same, every gear lifted 45 mm so the spacers and shafts are visible |
| `assembly_top.png` | Plan view, matches the baseplate template |
| `baseplate_template.pdf` | **1:1 drilling template**, US Letter portrait |
| `baseplate_assembly_guide.pdf` | bench reference: what sits on each shaft, spacer heights, fasteners. **Not to scale** |

The PDF must be printed at **100% / Actual size** — no page scaling, no
fit-to-page. It carries a 100 mm scale bar on each axis; measure both with a
rule before you drill. Regenerate it with `.\build.ps1 -Only baseplate_template.pdf`.

Render the assembly views with `.\build.ps1 -Group docs`.

## `out/_scratch/`

Calibration gauges, the backlash test jig, and superseded exports. Nothing in
there is part of the final build, and it is gitignored — but the gauges and the
test plate are re-runnable tools, not rubbish. Rebuild them with
`.\build.ps1 -Group calibration`.

## Print notes

Accuracy problem, not a strength problem — see the settings table in
[README.md](README.md). The three that matter most:

- **Walls = 4.** At module 1 a tooth is ~1.57 mm thick, so 4 walls makes it
  100 % perimeter. This decides your flank quality.
- **Z Seam = Random**, at least for pinions. A stacked seam puts a ridge on one
  tooth, which is the once-per-revolution drag spot found on the first test pair.
- **Don't print a pinion alone** — 17 mm layers give no cooling time. Batch them.

For the 196 mm final wheel: brim it, and consider `-D lighten=false`. Flatness
matters more than weight on that part, and the default lightening leaves ~4 mm
webs at this diameter.

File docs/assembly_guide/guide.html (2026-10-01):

ST-2048:1 · mechanics rev B · board rev C, 30-pin · 2026-09-27 Red light

# STJÄRNSPÅR

Sidereal camera tracker, 2048 : 1. Assembly, wiring, smoke test, first light.

Design and Qualitythe bench of Mike

ST-2048:11

measure it

assume it

This build has three measured numbers and several guessed ones. Where a step says measure, the design depends on it: the printer offsets, the bearing fit and the magnet gap were all found this way, and none of them can be predicted.

ST-2048:12

### Contents

Print first, assemble second. The calibration gauges set the numbers every later step depends on: BOREGAUGE picks the motor pinion, BEARINGGAUGE sets $BrgFit before the tower is printed, and the fit gauge already gave the 0.50 mm post/hole offset. PRINTING.md has the order and settings.

Build the polar wedge before the gearbox. One degree of polar misalignment drifts about 16 arcsec a minute, which is more than every gear error in this machine put together.

ST-2048:13

1

### Fasteners

ISO 10642 M3×84xcountersunk, motor

ISO 4762 M3×143xtower, into the disc

ISO 4762 M3×206xwheel clamp

M3×62xAS5600 board

ISO 4029 M3×42xpinion, lower hub

1/4"-20 UNC hex1x7/16" AF, full height

M5, to suit4xwedge adapter

ST-2048:14

2

### Metal parts

20d bright common3x4.88 mm, buy a box

5 mm ground, h61x65 mm, cut to 55

625ZZ 5×16×52xoutput shaft

6×2.5 diametric1xmust be diametric

3

### Parts you will need to 3D print

pinion.stl1x15T, D-bore variant

stage.stl2x120T + 15T

final_stage_gear.stl1x120T + 24T m2

final_wheel_96T_m21x196 mm OD

output_tower_*.stl1+13 dowels, 11.9 long

output_hub_*.stl1+1lower, upper

cap, washer, bracket1+1+1

SPACERS_shaft_0-43xuse S1, S2, S3 only

ST-2048:15

### What changed in Rev B

fixed in the CAD

Drawing Rev A for this guide turned up eight conflicts. All are fixed in star_tracker_gears.scad, rebuilt, and checked for interference in OpenSCAD. Two need your hands: countersink the plate, which is already cut, and cut the shaft to 55 mm. If you printed Rev A parts, reprint the tower halves, both hubs and the bracket.

1. KI 1
  Tower cone sat inside the plate. Rev A's 45° cone was 32 to 44 mm across inside a 22.4 mm hole, so the flange could never seat. Rev B: the halves clamp the plate. The flange is on top, a 41 mm disc is underneath, dowels cross the gap, and 3 × M3×14 thread-form into the disc. Step 13.
2. KI 2
  Shaft ran through the camera nut. Rev B: cut it to 55 mm, z −33 to 22. Step 14.
3. KI 3
  M3×10 motor screws bottomed out. Rev B: M3×8 flat head, 3.7 mm of thread. Step 5.
4. KI 4
  Screw heads under the S1 wheel. The wheel is 2.0 mm above the plate, over two motor screws and one M5 wedge hole. Rev B: countersink those holes by hand. Step 5, step 19.
5. KI 5
  Lower hub rubbed the tower. Rev B: a printed 7.2 × 1.0 washer sits on the bearing's inner race, and the hub is 1 mm shorter, so the wheel stays at 21.5 mm. Step 15.
6. KI 6
  Bracket had no axial stop. Rev B: it slides up until it stops on the clamp disc, so the 2.0 mm magnet gap comes from the parts. Step 18.
7. KI 7
  Grub-screw holes in gears that turn on fixed nails. Rev B: removed from both stage gear files. On Rev A prints, leave them empty. Step 6.
8. KI 8
  Camera nut pocket 2.2 mm deep. Rev B: the upper hub is 10 mm thick with a 5.9 mm pocket for a full-height nut. The wheel screws become M3×20. Step 17.

ST-2048:16

A

## Gearbox

Plate, nails, motor, then each stage from the motor outwards, then the output tower. Heights all measure from the top face of the plate.

1

### Check the plate, find its top

- Deburr every hole on both faces. Do not open up the three 4.9 mm nail holes; they are a light press.
- Seen from the top, S0 → S1 → S2 → S3 runs counter-clockwise. Mark TOP with a marker.
- Lay it on baseplate_template.pdf, printed at 100 %, and check every hole lines up.

ST-2048:17

2

### Pick and cut the nails

roll on glass

bent: reject

- 20d bright common only. Box nails and sinkers run a gauge thinner; galvanised coating is lumpy.
- Roll-test the box, keep the three straightest. The very straightest goes to S3: it carries the final pinion.
- Cut the point off, square and deburr the end. Lengths under the head: S1 20, S2 27, S3 33 mm.

ST-2048:18

3

### Press the nails in from underneath

square to the plate

leaning

- Turn the plate TOP face down. Support each hole on an open socket so the tip has somewhere to go, then press or tap until the head seats.
- Height above the top face: S1 15.7, S2 22.7, S3 28.7 mm.

S1 must stay under 19 mm. The 96T output wheel passes over S0 and S1 with its underside at 21.5 mm.

ST-2048:19

4

### Trim the motor shaft

- The pinion sits 2 to 9 mm above the plate, so the shaft ends about 9.5 mm above the plate: 13.8 mm above the motor's mounting face.
- Only cut if it is longer. Check the D-flat still covers the 6.3 to 13.3 mm band where the pinion's grub screw lands.
- Tape over the gap around the shaft first. Steel filings and a magnet rotor do not part.

ST-2048:110

5

### Mount the motor

KI 3 KI 4

- Pilot boss into the 23 mm hole. Connector on the side away from S4; the encoder bracket hangs there.
- Countersink the four holes from the top (90°, 6 mm across), then 4 × M3×8 flat head. That leaves 3.7 mm of thread in the motor.
- While the countersink is out: do the M5 wedge hole nearest S1 too (step 19).

Push a drill bit into a motor hole to gauge its depth before choosing a length. Thread engaged = length − 4.3, and it must be shorter than the hole. M3×10 needs 5.7 mm.

ST-2048:111

6

### Shaft 1

KI 7

spins free
on the nail

grub screw in a stage gear

- spacer 2.0, then stage.stl with the 120T wheel down.
- It should spin a full turn from a flick and wobble only as much as the nail.

ST-2048:112

7

### Motor pinion

- Use the bore variant that slid onto the motor shaft without force: 5.30, 5.45 or 5.60.
- Grub hole over the D-flat. Lower until the pinion's underside is flush with the S1 wheel's underside. It is 2 mm taller than the wheel on purpose and overhangs at the top.
- Run the M3 grub in and out once to form the thread, then tighten onto the flat.

Shaft 0 has no spacer. The 2 mm spacer would drop through the 23 mm motor hole, so the grub screw sets this height.

ST-2048:113

8

### Shaft 2

- spacer 8.5, then stage.stl, 120T down. It meshes with S1's 15T pinion.

Never fit a stock shaft collar at S2 or S3. The printed spacer is 10 mm across; a spacer 13 mm across touches the neighbouring wheel's tips.

ST-2048:114

9

### Shaft 3

- spacer 15.0, then final_stage_gear.stl: 120T down, coarse 24T module-2 pinion up.
- This pinion's radius sets short-exposure trailing. It goes on the straightest nail.

ST-2048:115

10

### Turn test

- Turn the S1 wheel with a finger. Motor, S2 and S3 should follow smoothly with a small, even click of backlash at each mesh.
- A tight spot once per pinion turn is a Z seam on one tooth. Reprint that pinion with Z Seam = Random.
- Look along each mesh: every wheel face sits inside its pinion's face.

Turn the train from the S1 end only. Once the output wheel is on, never turn the output by hand: that is 2048 turns of the motor for one of the wheel, and the teeth strip first.

ST-2048:116

11

### Dowels into the lower half

- Stand the lower half on its tube, disc face up. That is the face that meets the plate.
- Three dowels, 11.9 mm long: 4 in this half, 4.3 across the plate, 4 into the upper half. A 3 mm rod cut to length works too.
- No glue anywhere in the tower. The halves never touch each other; the screws clamp them to the plate.

ST-2048:117

12

### Press in the bearings

- Lower half: its pocket opens at the bottom of the tube. Upper half: at the top. Use a socket that fits the outer race, with firm thumb or vise pressure.
- Loose? Print again with a smaller $BrgFit. Needs a hammer? Larger.

ST-2048:118

13

### Clamp the tower to the plate

KI 1

- Lower half up under the plate at S4, dowels up through the 22.4 mm hole. Upper half down onto the dowels.
- 3 × M3×14 from above: through the flange and the plate, then they thread-form 5.7 mm into the disc. No nuts.
- Snug the three in turn. Flange and disc sit flat on both faces of the plate, and the tube stands square to it.

ST-2048:119

14

### Cut the output shaft

KI 2

- Ground 5 mm stock, not a nail. This one runs in bearings and carries the magnet.
- 55 mm: bottom end in the magnet cap at z −33, top end at z 22, above the hub grub (z 17.5) and below the camera nut (z 26.5). Chamfer both ends lightly.

ST-2048:120

15

### Washer, lower hub and shaft

KI 5

- hub_washer.stl (7.2 × 1.0) on the upper bearing's inner race. Hold it against the bearing first: it must not touch the shield.
- Lower hub on, register up. Shaft down through the hub and both bearings.
- Hub grub (M3, radial) finger-tight: the height is set in the next step.

Washer, inner race, hub and shaft all turn together, so the washer never wears. It only keeps the hub off the stationary tower rim.

ST-2048:121

16

### Magnet and cap

- Check the magnet is diametric: spin it flat beside a compass and the needle turns a full circle with it.
- Magnet flush into the pocket in the cap's end face. Press the cap up onto the shaft until the shaft bottoms. Do not glue it yet; step 48 sets its rotation.
- Slide the shaft until the cap's face is 16.0 mm below the tower's bottom face (caliper depth rod), then tighten the hub grub.

ST-2048:122

17

### Output wheel and camera platform

KI 8

- 96T wheel over the 22 mm register. It is located by the register, not by its own bore.
- Full-height ¼"-20 nut into the hex pocket under the upper hub, then the hub on top.
- 6 × M3×20 through hub and wheel into the lower hub (thread-forming, 5 mm engagement). Tighten in a star pattern.
- The wheel face must sit inside the 24T pinion's face: 21.5 to 26.5 mm inside 20 to 27 mm.

ST-2048:123

18

### AS5600 and its bracket

KI 6

- Solder a 5-wire lead to the breakout first: GND, VCC, SDA, SCL, DIR.
- Board to the bracket underside, chip up into the window: 2 × M3×6, thread-forming.
- Push the bracket up the tower spigot until it stops on the clamp disc. That puts the die 2.0 mm from the magnet. Step 47 confirms it with the AGC reading; then a dab of hot glue holds it there.

At 3.3 V the AS5600 wants its VDD5V and VDD3V3 pins tied together. Many breakouts have a solder bridge for this; check yours.

ST-2048:124

19

### Wedge adapter

KI 4

- 4 × M5 on a 50 mm circle, centred on the output axis, not the plate's middle. That is where the camera load is.
- The adapter needs a 42 × 7 mm relief for the tower's clamp disc, and a hole at least 32 mm across with about 45 mm of depth for the bracket and its lead.
- The M5 hole nearest S1 is under the S1 wheel. Anything above the plate there must stay under 1.5 mm: countersunk, or leave that bolt out.

ST-2048:125

20

### Camera

- GoPro frame and ¼"-20 adapter. At most 10 mm of thread below the platform top.
- Bias the balance so the load always pulls the same way. A perfectly balanced camera lets the teeth rattle across the backlash.

From here on, the platform moves only under power (jog, slew, track). Turning it by hand back-drives 2048 : 1.

ST-2048:126

### Every mesh gets its own height band

A pinion always collides with any wheel next to it, meshing or not, so four meshes need four bands. Spacers (dark) set each wheel's height. Every pinion is 7 mm tall against a 5 mm wheel so the wheel stays inside it.

ST-2048:127

B

## Controller board

All through-hole, every module in a socket. Solder in rounds, lowest parts first, and test after each round (section C) before the next.

### The finished board

Drawn from the KiCad layout, so every part is where the board puts it. Modules shown seated in their sockets. This is board Rev C, laid out for the 30-pin ideaspark ESP32 + OLED; the drawing follows the layout on every build.

ST-2048:1

4

### Electronic parts for the board

Each card shows the part, its schematic symbol, and the letter it carries on the silkscreen: Q4 is the fourth transistor, R12 the twelfth resistor.

R1–R1917xResistors, ¼ W. 10k ×7, 1k ×4, 100k ×2, 4.7k, 330R, and the 1 % pair 100k + 18k. R10, R11 stay empty.

C2 C4 C6 C8 C10 C12 C13 C15–C1710xCeramic capacitors, 100 nF, marked 104. No polarity.

C1 C3 C5 C7 C9 C116xElectrolytic capacitors. 470 µF ×2 (C3 low-ESR), 220 µF low-ESR, 100 µF ×3 (C11 low-ESR). Polarised.

D11xZener diode, 1N4744A 15 V. Clamps Q1's gate.

D21xTVS diode, P6KE20CA. Bidirectional, fits either way.

D31xSchottky diode, 1N5822 3 A. The buck's catch diode.

LED1 LED2 LED33xLEDs, 3 mm. Green ×2 (5 V, camera), red ×1 (status).

Q1 Q22xP-channel MOSFET, IRF4905, TO-220. Reverse polarity and the camera switch.

Q3 Q52xNPN transistor, 2N3904, TO-92. The arrow points out.

Q41xPNP transistor, 2N3906, TO-92. The arrow points in. Looks just like the 2N3904; read the print.

U21xRegulator, LM2596T-5.0, TO-220-5, with a clip-on heatsink.

L11xInductor, 33 µH, 3 A or more, 12 mm radial.

F11xFuse, 3 A 5×20 mm, in two PCB clips.

SW11xTactile switch, 6 mm. CONFIG and wake.

J1 J3 J43xScrew terminals, 5 mm pitch. 2-way ×2, 4-way ×1.

J21xUSB-A receptacle, through-hole, horizontal. Camera power.

J5 J7–J11 JP3–JP51xMale header strip, 1×40, 2.54 mm. Cut to length.

J20 J21 J30 J31 J65xFemale sockets, 2.54 mm: 1×15 ×2 for the 30-pin ESP32, 1×8 ×2, 1×6.

JP4 JP52xJumper shunts, 2.54 mm. MS1 and MS2 to GND.

Modules go in the sockets last, after section C: ESP32 + OLED, TMC2209, DS3231 with a CR2032. Plus four M3 standoffs for the corners.

ST-2048:1

21

### Which board?

Build board Rev C. It is laid out for the module in hand: the 30-pin ideaspark ESP32 + 0.96" OLED, rows 27.94 mm apart. Rev B was drawn for a 38-pin DevKitC and does not fit it.

The pin map was settled by the pin check (step 44): the OLED shares the sensor I²C bus on GPIO 21/22, so WAKE stays on GPIO 4, and the module has no PSRAM. Using a different ESP32 board? Run the pin check on it first.

Everything in this section is about part orientation, which does not change between revisions. Where a step names a pin, it uses the signal name printed beside the socket (CAM_EN, GPS_EN, VBAT_SENSE), not a GPIO number.

ST-2048:128

22

### Read the silkscreen

- The square pad is the one to find: pin 1 of an IC or socket, + of an electrolytic, K (cathode) of an LED or diode.
- Nothing on this board is fitted by guessing. If a part does not match its outline, stop.

ST-2048:129

23

### Round 1: resistors

Value | Refs
10k | R1 R3 R4 R9 R13 R16 R18
100k | R5 R19 | hold camera and GPS off
4.7k | R12 | WAKE pull-up, always fit
1k | R2 R6 R7 R17
330R | R8 | red status LED
100k 1%, 18k 1% | R14, R15 | battery divider
leave empty | R10 R11 | the DS3231 module has its own

Measure each resistor with the meter before it goes in. It is faster and more reliable than reading bands.

ST-2048:130

24

### Round 1: small caps and D1

- 10 × 100 nF ceramics, marked 104. No polarity.
- D1 1N4744A zener stands like a resistor, stripe at the top. The bent top lead goes into the square K pad; the body stands over the circle.

ST-2048:131

25

### Round 2: power input

- Q1 IRF4905: metal tab toward the bold bar, pin 1 (gate) in the square pad. Printed face toward you, the legs read G D S.
- D2 P6KE20CA is bidirectional, so either way up.
- F1 clips with stop tabs out, C1 470 µF (next panel), J1 terminal with its openings to the board edge.
- Then go to Test 0 to Test 2.

Q1 is where reverse-polarity protection is won or lost: drain to the supply, source to the load. The footprint fixes that, as long as pin 1 is in the square pad.

ST-2048:132

26

### Round 3: the 5 V buck

- U2 LM2596T-5.0: legs 1, 3, 5 in one row, 2 and 4 in the other; pin 1 square. Fit the clip heatsink.
- L1 33 µH, no polarity. D3 1N5822 stands like D1: stripe up, bent lead to K.
- C3 470 µF and C5 220 µF must be the low-ESR ones. Long leg into the square + pad, stripe away from it.
- R2 + LED1 (next page). Then Test 3.

ST-2048:133

27

### Round 4: camera switch, LEDs

- Q2 IRF4905 as Q1. Q3 2N3904 (next panel). C7 100 µF 16 V, J2 USB-A, J3 terminal.
- LED1, LED2 green, LED3 red: flat side and short leg into the square K pad.
- Then Test 4.

TO-220 tabs are live. Q1's tab is the 12 V input, Q2's is the camera 5 V, U2's is ground. Keep U2's heatsink clear of both.

ST-2048:134

28

### Round 5: GPS switch

- Q5 2N3904 NPN and Q4 2N3906 PNP. Flat face over the flat edge of the outline.
- Read the print on each one before it goes in. They look identical and swapping them fails quietly.
- C17 100 nF if not already in. Then Test 5.

ST-2048:135

29

### Round 6: sockets, headers, the rest

- C11 100 µF low-ESR sits at the driver socket (VMOT). C9 100 µF 10 V on 3V3.
- J4 motor terminal, SW1, headers J5 J7 J8 J9 J10 J11, jumpers JP3 JP4 JP5.
- Sockets: ESP32 (2 × 1×15), TMC2209 (2 × 1×8), DS3231 (1×6). Plug the module in, tack the two end pins of each row, check it sits square, then solder the rest. Unplug the module afterwards.
- Jumpers JP4, JP5 to GND: UART address 0, which the firmware expects. JP3 open.

ST-2048:136

C

## Smoke test

Nothing expensive goes in until every rail reads right. A bench supply with a current limit, or a 12 V bulb in series with the lead, turns a mistake into a reading instead of a smell.

30

### Test 0: Look, then measure

- Look for bridges and dull joints under a light. Clean the flux off.
- Unpowered, meter on Ω: J1 +12V to GND climbs as C1 charges. 5 V to GND and 3V3 to GND (socket pins) are not below 10 Ω.

A steady reading under 10 Ω is a short. Find it before any power goes in.

ST-2048:137

31

### Test 1: First power, current-limited

- After round 2. Supply at 12 V, 100 mA limit into J1.
- Q1's source leg reads the input voltage, within 0.1 V.

ST-2048:138

32

### Test 2: Reverse polarity

- Swap the leads at J1, still current-limited. The rail reads 0 V and nothing gets warm.
- If the rail shows −12 V, Q1 is in backwards. Stop here.

ST-2048:139

33

### Test 3: The 5 V rail

- After round 3. 4.9 to 5.1 V at C5 and at the ESP32 socket's VIN pin. LED1 lights.
- Idle draw at 12 V is around 10 to 20 mA: the regulator's own current plus LED1.

ST-2048:140

34

### Test 4: Camera switch

- After round 4. J3 reads 0 V at rest: the camera is off by default.
- Hold a 1 kΩ resistor from the socket's VIN pin to its CAM_EN pin. J3 and the USB-A read 5 V, LED2 lights. Take it away and they drop to 0.

ST-2048:141

35

### Test 5: GPS switch

- After round 5. The same 1 kΩ from VIN to the GPS_EN pin: J9 pin 2 reads about 4.8 V. Without it, 0 V.

ST-2048:142

36

### Test 6: Battery divider

- VBAT_SENSE = input × 18 / 118. 12.0 V in gives 1.83 V, a full 14.6 V LiFePO4 gives 2.23 V. Both are safely under the ESP32's 3.3 V.

ST-2048:143

37

### Test 7: Warm check, then the ESP32

- Five minutes powered with nothing fitted. U2 and Q1 barely warm.
- Power off. Fit the ESP32 only: USB toward the arrow, its pin 1 at the socket's 1. If it does not line up, stop.
- Power on. 3.2 to 3.4 V at J7 pin 2, J10 pin 2, the DS3231 socket's VCC and the driver socket's VIO. The OLED may light.

3.3 V comes out of the ESP32 module's own regulator. With no module fitted, the 3V3 net reads nothing, and that is correct.

ST-2048:144

38

### Test 8: The driver and the clock

- Power off. Motor wired to J4 before the driver goes in (step 40).
- TMC2209: match EN on the module to EN on the silkscreen. On BTT modules the chip is on the underside, which is normal. Turn the VREF pot to its low end for now.
- DIAG: no vendor brings it out on the header. Flying lead from the module's DIAG pad to J5 pin 1.
- DS3231 (ZS-042) with a CR2032, in the order printed: 32K SQW SCL SDA VCC GND. Its charging circuit is harmless at 3.3 V.

Never plug or unplug the motor with power on. The driver dies from the inductive kick, and C11 must be fitted at VMOT before the driver sees 12 V.

ST-2048:145

D

## Wiring

The board, the battery, the motor, the encoder, the GPS and the camera.

39

### The whole loom

Fritzing, breadboard view. Source: hardware/fritzing/star_tracker_wiring.fzz, generated by gen_fritzing.py from the KiCad layout.

- Battery 12 V LiFePO4 → inline 3 A fuse → XT60 → J1, + to +12V. With solar, feed from the charge controller's load output.
- Board fuse F1 is also 3 A. The inline fuse protects the lead.

ST-2048:146

40

### Motor coils

- Wire colours vary between pancake motors, so measure. One pair to A1 A2, the other to B1 B2 on J4.
- Wrong direction on first spin? Swap A1 and A2 only, with power off.

ST-2048:147

41

### Encoder lead

J7 | Board | AS5600
1 | GND | GND
2 | 3V3 | VCC
3 | SDA | SDA
4 | SCL | SCL
5 | GND | DIR

- Under about 30 cm, SDA and SCL twisted with a ground. The bus runs at 400 kHz.
- The bracket and sensor stay still; only the magnet turns. This lead never has to follow the camera.

ST-2048:148

42

### GPS and the PPS lead

- The GY-NEO6MV2's own 4-wire cable plugs into J9 pins 2 to 5 (VCC RX TX GND), in the module's own order.
- PPS is not on its header. It drives the on-board PPS LED. Solder a flying lead from that LED's driven side to J9 pin 1.
- Pick the pad that swings to about 3 V once a second after a fix. If you see only about 2 V, you are on the LED side of its resistor: move to the other end.
- The antenna goes where it sees sky, outside the IP54 box.

PPS measures the crystal and sets the clock to under a second. It does not steer tracking: 20 ppm over a 12-hour night is 3.6 arcsec.

ST-2048:149

43

### Camera cable

- J2 USB-A → short right-angle USB-C → HERO6. J2's data lines are shorted, which tells the camera it may draw full charge current.
- Route it with the platform at the start angle. A night is 180.5° of travel, so leave a slack loop that reaches both ends without pulling on the camera.
- Tie the cable to the platform so the loop, not the USB-C plug, takes the bend.

Measure the real arc the loop allows. It becomes TRAVEL_MIN_DEG / TRAVEL_MAX_DEG in step 50.

ST-2048:150

E

## First power-up and calibration

today works with a sketch already in the repo. planned needs the firmware laid out in FIRMWARE.md, which is not written yet.

44

### Pin check

today

- Flash firmware/pincheck/pincheck.ino. Arduino IDE, board "DOIT ESP32 DEVKIT V1", serial monitor at 115200. Nothing else needs to be connected.
- It scans three I²C buses and names what answers, then prints PSRAM.

You see | Means
0x3C on GPIO 21/22 | OLED shares the sensor bus. WAKE stays on GPIO 4.
0x3C on GPIO 4/15 | Those pins are taken. WAKE moves to the upper row.
PSRAM: none | WROOM, as expected.
PSRAM: present | WROVER. GPIO 16/17 are taken and the driver UART moves.

Result for this build (2026-09-27): ESP32-D0WD-V3, 4 MB flash, PSRAM none; 0x3C on GPIO 21/22, nothing on 4/15. Board Rev C is laid out from it. Run it again only if you change ESP32 boards.

ST-2048:151

45

### First spin, and which way

today

- sidereal_drive.ino drives STEP 25, DIR 26, EN 27, which the planned pin map keeps.
- VREF pot near its low end. Motor buzzes but does not turn? Raise it a little.
- Wrong way round? Change digitalWrite(PIN_DIR, …) or swap A1/A2 with the power off.

Without UART setup the TMC2209 runs standalone. With MS1 and MS2 at GND that is 1/8 microstepping, not the 1/32 the sketch assumes, so the output turns 4 × sidereal, about 1° a minute. That is fine for seeing the direction, and it is not tracking.

ST-2048:152

46

### Driver current and microsteps

planned

- Over UART: run current 300 to 400 mA. There is a 250 × torque margin, and low current means less vibration and heat.
- MRES 1/32 for tracking, 1/8 for slews. The position counter always stays in 1/32 units.
- Once UART sets the current, the VREF pot does nothing.

ST-2048:153

47

### Magnet gap

planned

- Read AGC, MAGNITUDE and the MD / ML / MH status bits. Shown on the OLED and the phone page.
- Want: MD = 1, ML = 0, MH = 0, AGC near mid-scale (about 64 of 128 at 3.3 V).
- Slide the bracket to get there, then lock it with a dab of hot glue.

ST-2048:154

48

### Encoder zero

planned

- Park the platform at the start angle. Turn the magnet cap on the shaft until the raw reading is near 1024.
- The 180.5° sweep then ends near 3080 and never crosses the 0 / 4095 seam, so the firmware needs no wrap handling.

ST-2048:155

49

### Clock and site

planned

- Set the DS3231 from the phone's clock (POST /api/time), or let TIME_SYNC take it from a GPS fix.
- Put your latitude and longitude into the schedule's site. The default is 0, 0. With a GPS fix, the tracker overrides it each night.
- Watch rtc_drift_s for a few nights before deciding the clock needs correcting at all.

ST-2048:156

50

### Travel limits

planned

- Jog to each end of the arc the camera cable allows (step 43) and note the encoder angle.
- Set TRAVEL_MIN_DEG / TRAVEL_MAX_DEG in include/config.h. They are compile-time on purpose, so a phone cannot widen them.
- A schedule that would run past them is refused at upload, with the reason.

ST-2048:157

51

### Backlash

planned

- Start with BACKLASH_USTEPS = 10000. The estimate from 0.35 mm on the final mesh is about 7,600, or 750 arcsec.
- Run repeat_test: orient, short track, rewind, read the encoder at the start angle, N times. It reports mean and σ of the return error in arcsec.
- Adjust until the mean return error sits near zero.

The start angle is always approached going forward. Stop on a reverse stroke and the first minutes of tracking take up the backlash as drift.

ST-2048:158

52

### Camera profile

planned

- Run discover. It joins the HERO6, dumps its /gp/gpControl settings tree and serves it at /api/camera/dump.
- Fill camera_profile.json from your camera's own tree. The IDs in FIRMWARE.md are placeholders.
- Three things to find out on the bench: does wake-on-LAN wake it, what it draws in standby, and whether it stays rejoinable after the ESP32 leaves mid-record.

ST-2048:159

53

### First light

today

- Open-loop drive, a 50 mm lens, one 5-minute exposure. Measure the trailing.
- Only then decide what to fix. Upgrading shaft 3 to ground stock is the first mechanical step if the numbers call for it.

The encoder in this design is for scheduling and stall detection. Using it to correct tracking before you have trailing data solves a problem you have not measured.

ST-2048:160

F

## How to use

Set it up at dusk once, then leave it. The phone page and the night report reflect the planned firmware.

54

### Set up and polar align

- Level the tripod. Tilt the wedge to your latitude and point the output axis north.
- Sight Polaris down the axis. Aim for 0.25° or better.

ST-2048:161

55

### Load the camera

- Camera on, cable tied, slack loop free to swing.
- Bias the balance so the load pulls one way through the whole sweep. That keeps the mesh on one flank.
- Card empty, camera battery charged. It still runs on USB, and the battery rides through a hiccup.

slightly
off-balance

perfectly
balanced

ST-2048:162

56

### Configure from your phone

- Press CONFIG (SW1). The tracker raises its own Wi-Fi network for 10 minutes.
- Join it, open the page. Upload a schedule: site, start and stop events (dusk and dawn with offsets), start angle, camera profile.
- A bad schedule comes back with every error listed. One that would pass the travel limits is refused.
- Values on the example screen are illustrative.

ST-2048:163

57

### Walk away

- It sleeps until the dusk alarm, checks itself, takes a GPS fix, slews to the start angle going forward, starts the camera, then tracks.
- At dawn it stops the camera, rewinds with an overshoot and comes forward to the start, then sleeps.
- Camera or GPS trouble is logged and the night tracks anyway. A stall, encoder disagreement over 2° or a flat battery stops the motor first, then the camera.

ST-2048:164

58

### Next morning

- Read the night report: planned against actual start and stop, the largest encoder disagreement, lowest battery, camera result, every warning.
- Encoder disagreement over 0.5° is a warning worth a look; the train may be slipping.
- Keep the reports. When something odd happens on Tuesday, you want Tuesday's file.

ST-2048:165

59

### Care

jog under power

turn the platform
by hand

power off, then
the motor plug

unplug the motor
while powered

Symptom | First look
Drift from the first minutes | Polar alignment, then the forward approach to start
Once-per-turn trailing wobble | Shaft 3 nail straightness, the 24T pinion
FAULT at boot | Encoder not answering: J7 lead, magnet gap
Night skipped, no fault | Battery low, schedule invalid, or no twilight at your latitude
No frames, tracking fine | Camera profile IDs, wake-on-LAN, camera battery

ST-2048:166

### The numbers

Train | 15→120, 15→120, 15→120 (module 1), 24→96 (module 2): 8 × 8 × 8 × 4 = 2048 : 1
Microsteps per sidereal day | 13,107,200 at 1/32 (200 × 32 × 2048)
Step interval | 6573.80 µs, 152.13 steps/s, motor 1.426 rpm, 0.099 arcsec per microstep
Centre distances | 67.5 / 67.5 / 67.5 / 120.0 mm
Shafts (x, y) | S0 (0, 0) · S1 (67.5, 0) · S2 (67.5, 67.5) · S3 (0, 67.5) · S4 (0, −52.5)
Output backlash | ≈ 750 arcsec, 0.208°. BACKLASH_USTEPS 10,000 to start
One night | 12 h, 180.5° of output. About 43 Wh, 69 % of it the camera
Magnet to die | 2.0 mm (window 0.5 to 3.0)

ST-2048:167

G

## Appendix: schematics

The whole system as one diagram, the controller board as blocks, then the board's full schematic straight from KiCad.

### G1 · System wiring, schematic view

Fritzing, schematic view of the same sketch as section D. Each external part sits level with the board pins it meets, so every wire is one straight line.

Harness | Board | Far end | Wires
Power | J1 +12V, GND | battery via 3 A inline fuse | red through the fuse, black direct
Motor | J4 A1 A2 B1 B2 | NEMA 17, coil A and coil B | pairs found with a meter (step 40)
Encoder | J7 GND 3V3 SDA SCL DIR | AS5600 GND VCC SDA SCL DIR | DIR is tied to GND on the board
GPS | J9 PPS VCC RXD TXD GND | GY-NEO6MV2, PPS from its LED | module's own 4-wire cable + one lead
Camera | J2 USB-A | HERO6 USB-C | short right-angle cable, slack loop

ST-2048:168

### G2 · Controller board, logical diagram

- Three rails. 12 V from the battery through F1 and Q1; 5 V from the LM2596 buck; 3.3 V from the ESP32 module's own regulator, about 20 mA of extra load.
- Two loads are switched and off by default: the camera's 5 V (CAM_EN) and the GPS's 5 V (GPS_EN). Pull-downs hold both off while the ESP32 boots.
- One wake line takes both the RTC alarm and the CONFIG button, wired-OR on a single 4.7k pull-up. Firmware tells them apart from the RTC's alarm flag.
- Signal names, not GPIO numbers: FIRMWARE.md §4 maps each to its GPIO for board Rev C.

GPS UART, fixed. Rev B named the nets GPS_TX / GPS_RX and wired the ESP32's transmit to the module's TXD. design.py now names them by direction, ESP_TX_GPS_RX and GPS_TX_ESP_RX, and sends the ESP32's TX (GPIO 5) to J9 pin 3, the module's RXD. Board Rev C carries the fix.

ST-2048:169

### G3 · Controller board, full schematic

Rev C · 30-pin module

+−⤢

From hardware/star_tracker_ctrl/star_tracker_ctrl.kicad_sch via kicad-cli. Parts are joined by net label in KiCad; the coloured lines redraw those connections for this page (one colour per signal net; faint dashed grey for GND and the power rails). Drag to pan, scroll or pinch to zoom. The text is real text, so the browser's find works on it.The drawing is vector: zoom in on it as far as you like, and search its text.

Board Rev C, as generated from hardware/design.py. Regenerate the board and rebuild the guide, and this page follows.

ST-2048:170

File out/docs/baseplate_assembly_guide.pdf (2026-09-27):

Baseplate assembly guide | NOT TO SCALE - drill from baseplate_template.pdf

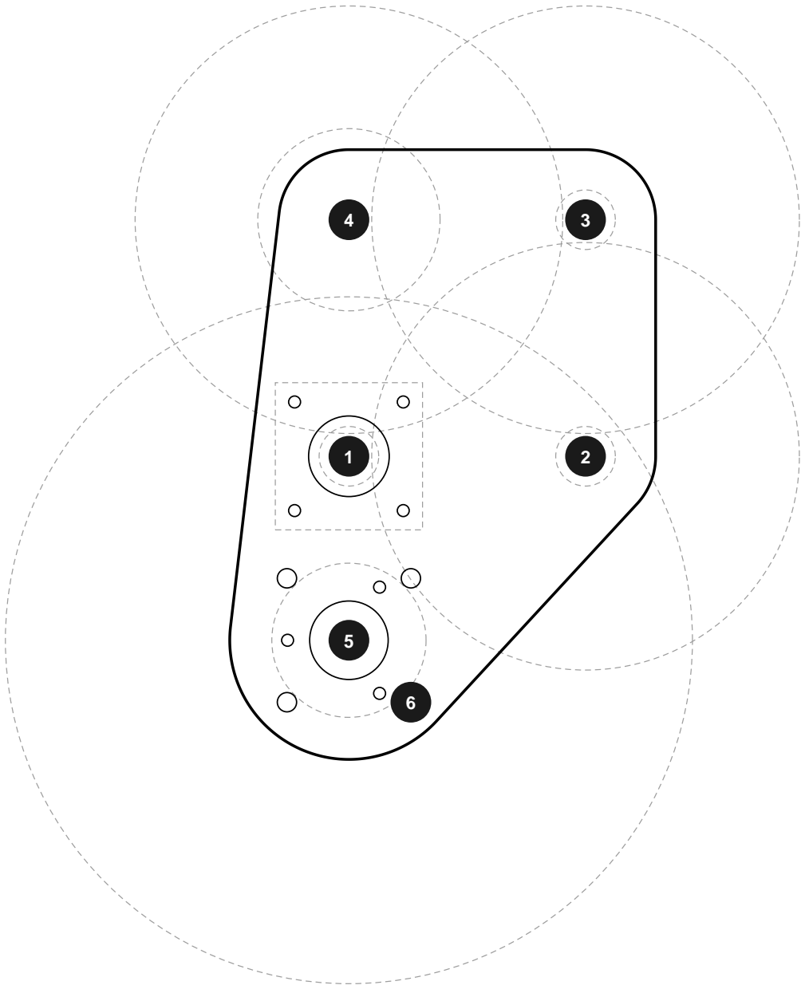
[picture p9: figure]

Dashed = parts that sit above the plate. They overhang it by design.

# | Shaft | Spacer | Sits on it (bottom to top) | Fasteners

1 | S0 motor | - | NEMA17 below plate; pinion.stl above | 4 x M3x8 flat head, countersunk
2 | S1 | 2 mm | spacer, then stage.stl (120T + 15T) | 20d nail shaft, head under the plate
3 | S2 | 8.5 mm | spacer, then stage.stl (120T + 15T) | 20d nail shaft, head under the plate
4 | S3 | 15 mm | spacer, then final_stage_gear.stl | 20d nail shaft, head under the plate
5 | S4 output | - | tower halves clamp the plate, 2x625ZZ, shaft, washer, hubs, 96T wheel 3 x M3x14 into the disc; 6 x M3x20 hub clamp
6 | wedge | - | tripod / wedge adapter, below plate | 4 x M5 on dia 50

Notes
Only THREE of the five printed spacers get used - S1 2.0, S2 8.5, S3 15.0. S0's would fall through the dia 23 motor bore (pinion height is set by its grub screw); S4's job is done by the bearing tower.
Nails go in from UNDERNEATH, head against the plate's underside. Cut the point off and square the end.
Trim the NEMA17 shaft to ~10 mm above the plate. At full 24 mm length it fouls the 96T output wheel.
Countersink the 4 motor holes: socket-cap heads hit the S1 wheel 2.0 mm above the plate. M3x8 flat head leaves 3.7 mm of thread; M3x10 bottoms out in the motor. The M5 wedge hole nearest S1 is also under the S1 wheel: countersink it or leave that bolt out.
Nothing over dia 13 mm may sit inline at S1-S3 - a stock 5 mm shaft collar will hit the neighbouring wheel.
Rewind then approach the start angle FORWARDS; the train has ~750 arcsec of backlash at the output.

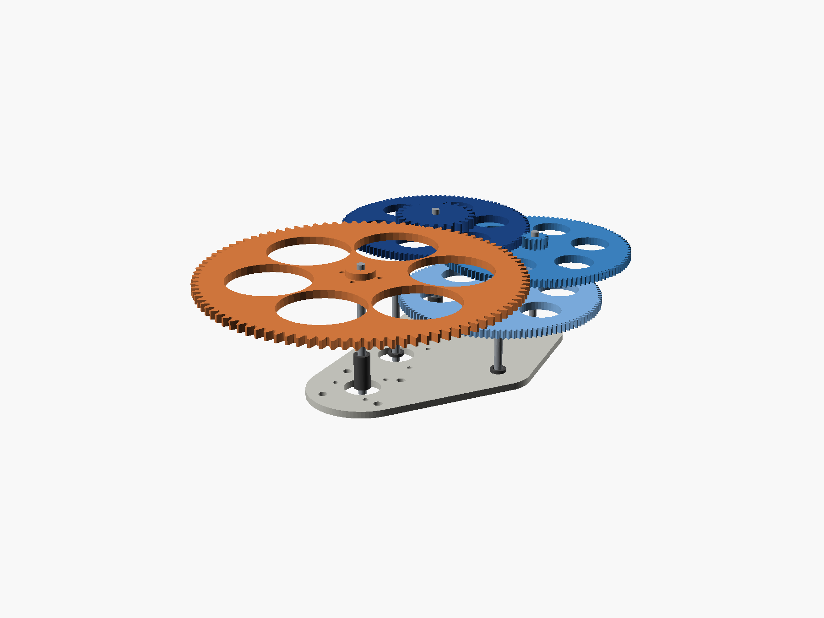
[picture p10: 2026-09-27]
out/docs/assembly_exploded.png

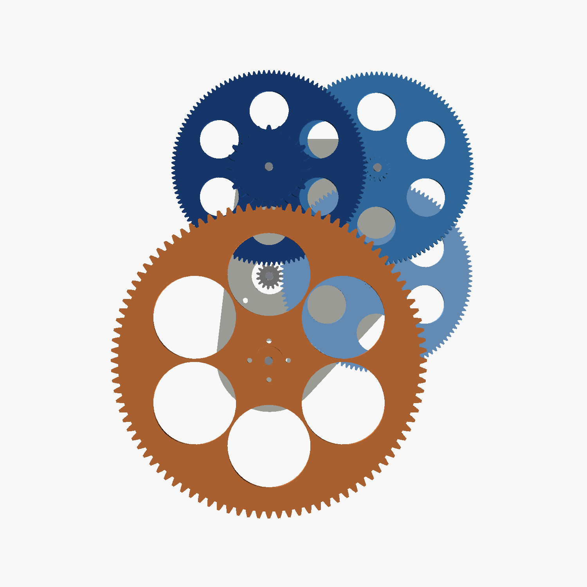
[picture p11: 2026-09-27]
out/docs/assembly_top.png

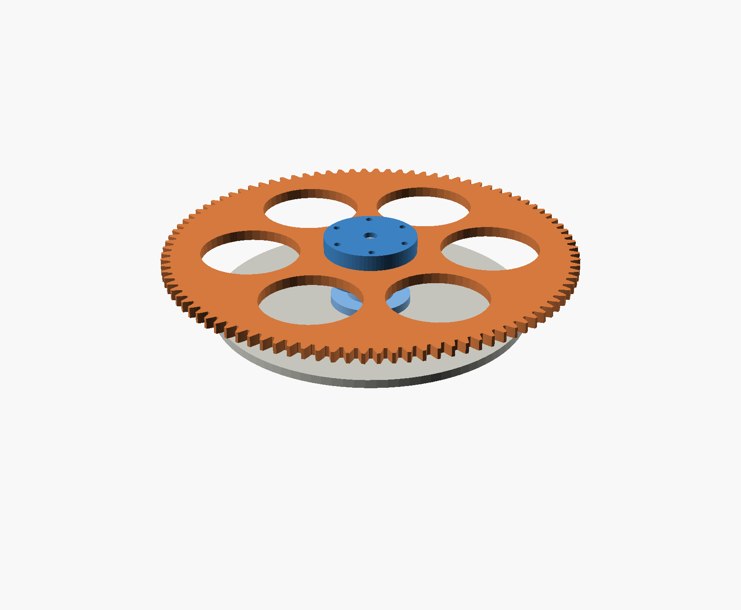
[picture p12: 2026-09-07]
out/docs/encoder_assembly.png

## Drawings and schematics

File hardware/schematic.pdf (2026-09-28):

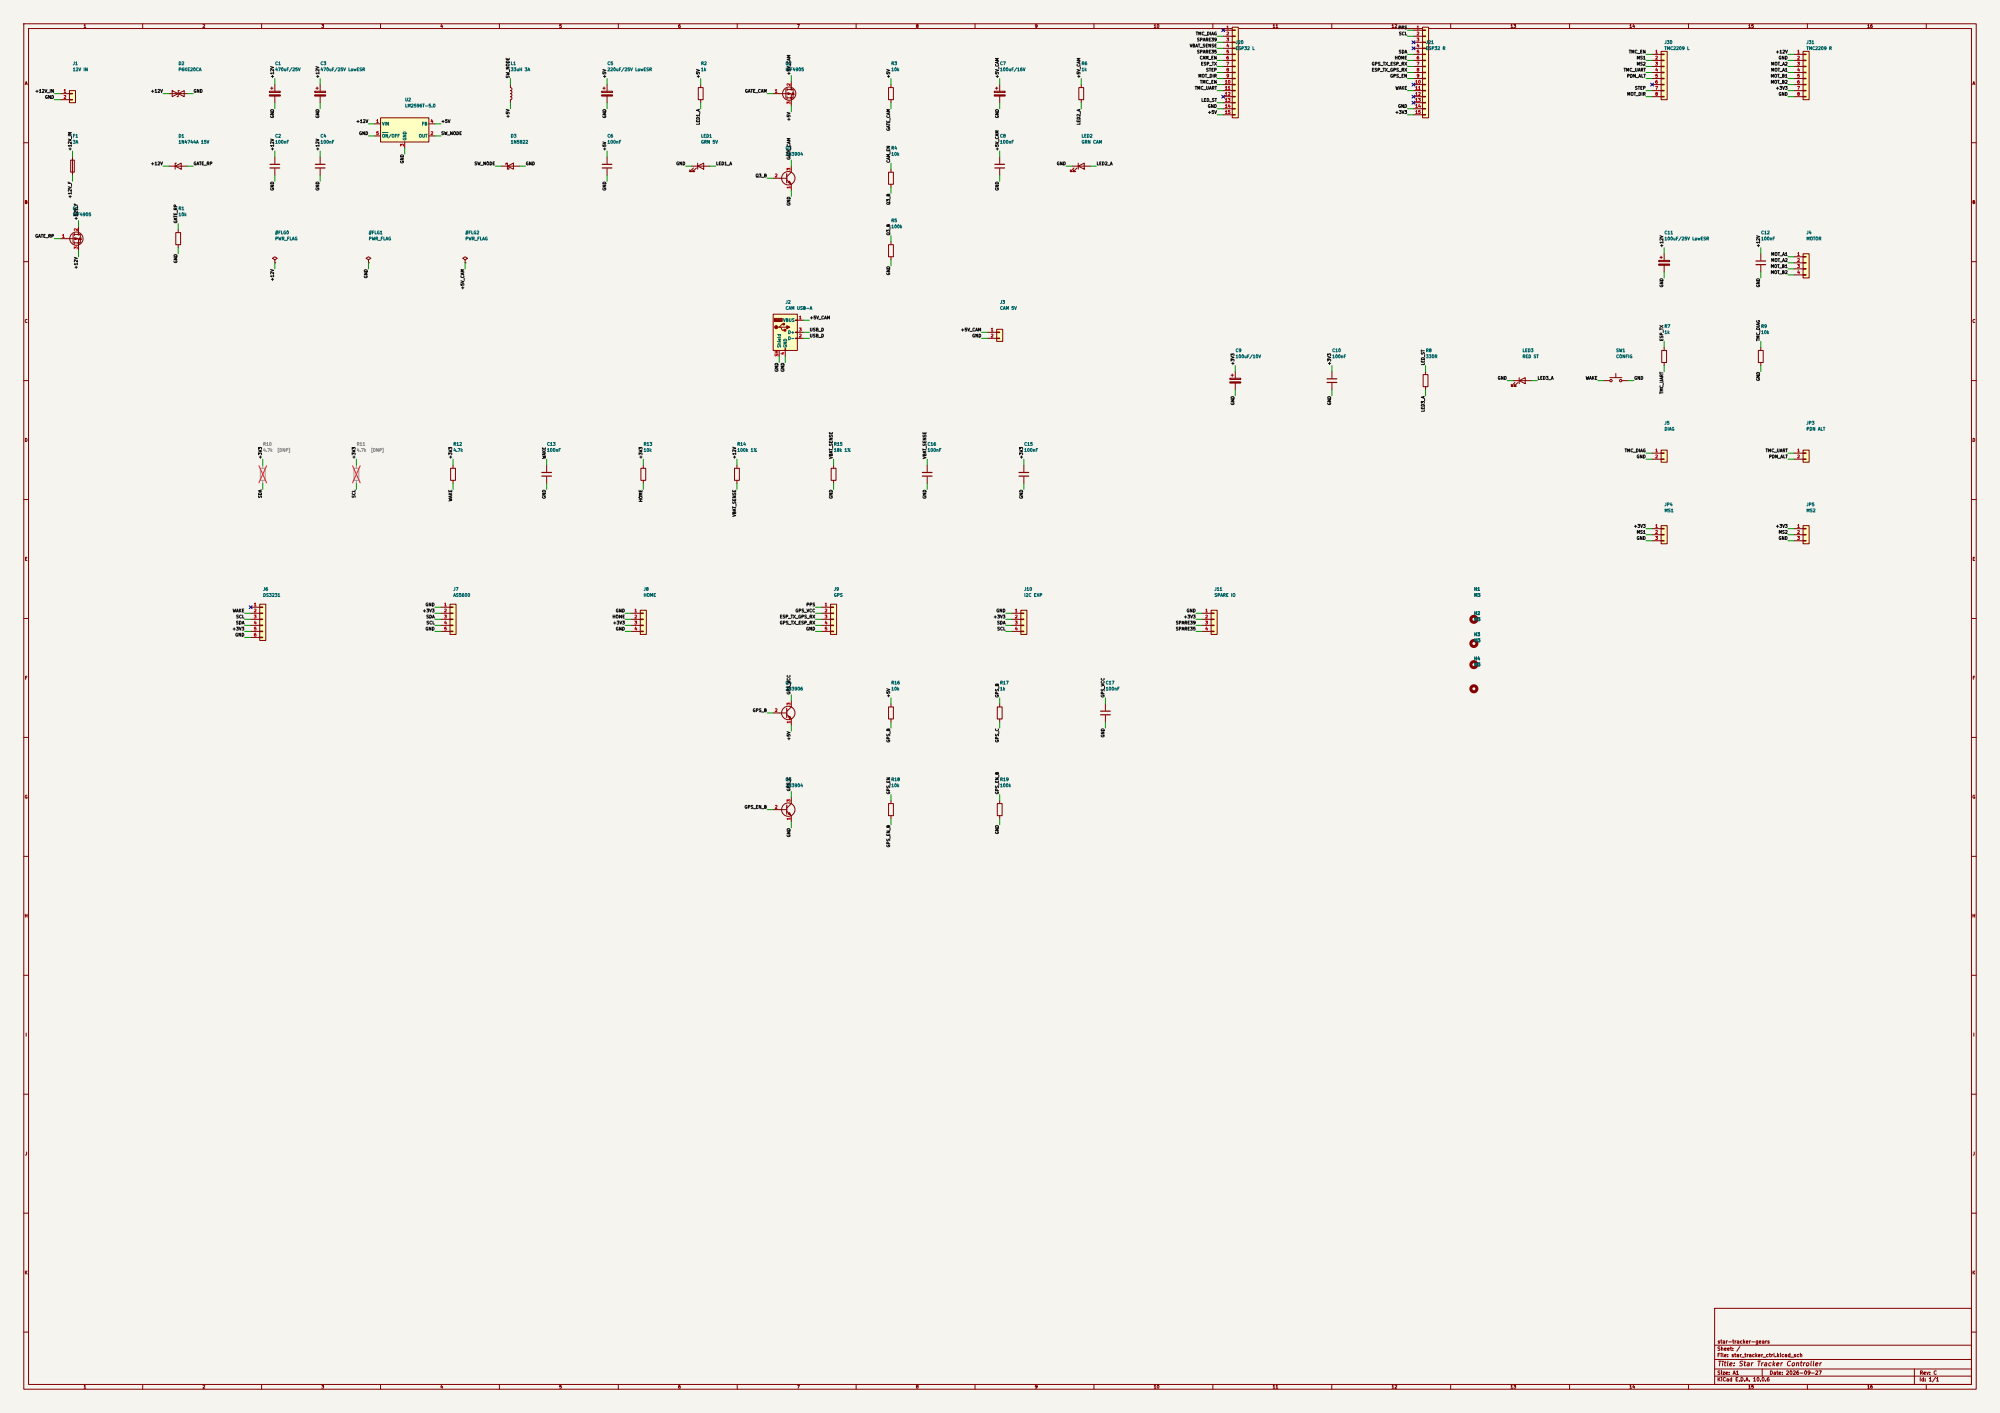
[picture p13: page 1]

star-tracker-gears
Sheet: /
File: star_tracker_ctrl.kicad_sch
Title: Star Tracker Controller

Size: A1 | Rev: C
KiCad E.D.A. 10.0.6 | Id: 1/1

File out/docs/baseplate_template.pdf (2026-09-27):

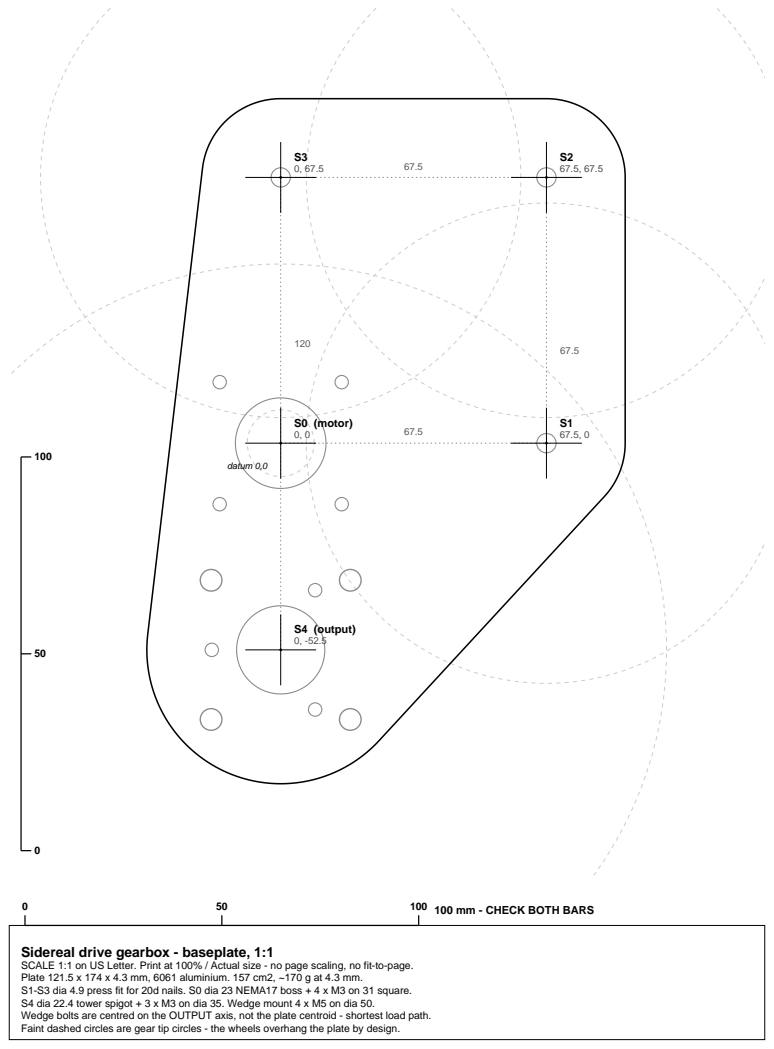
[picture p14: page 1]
S0 (motor) 0, 0; S4 (output) 0, -52.5; datum 0,0; 100 100 mm - CHECK BOTH BARS

Sidereal drive gearbox - baseplate, 1:1
SCALE 1:1 on US Letter. Print at 100% / Actual size - no page scaling, no fit-to-page.
Plate 121.5 x 174 x 4.3 mm, 6061 aluminium. 157 cm2, ~170 g at 4.3 mm.
S1-S3 dia 4.9 press fit for 20d nails. S0 dia 23 NEMA17 boss + 4 x M3 on 31 square.
S4 dia 22.4 tower spigot + 3 x M3 on dia 35. Wedge mount 4 x M5 on dia 50.
Wedge bolts are centred on the OUTPUT axis, not the plate centroid - shortest load path.
Faint dashed circles are gear tip circles - the wheels overhang the plate by design.

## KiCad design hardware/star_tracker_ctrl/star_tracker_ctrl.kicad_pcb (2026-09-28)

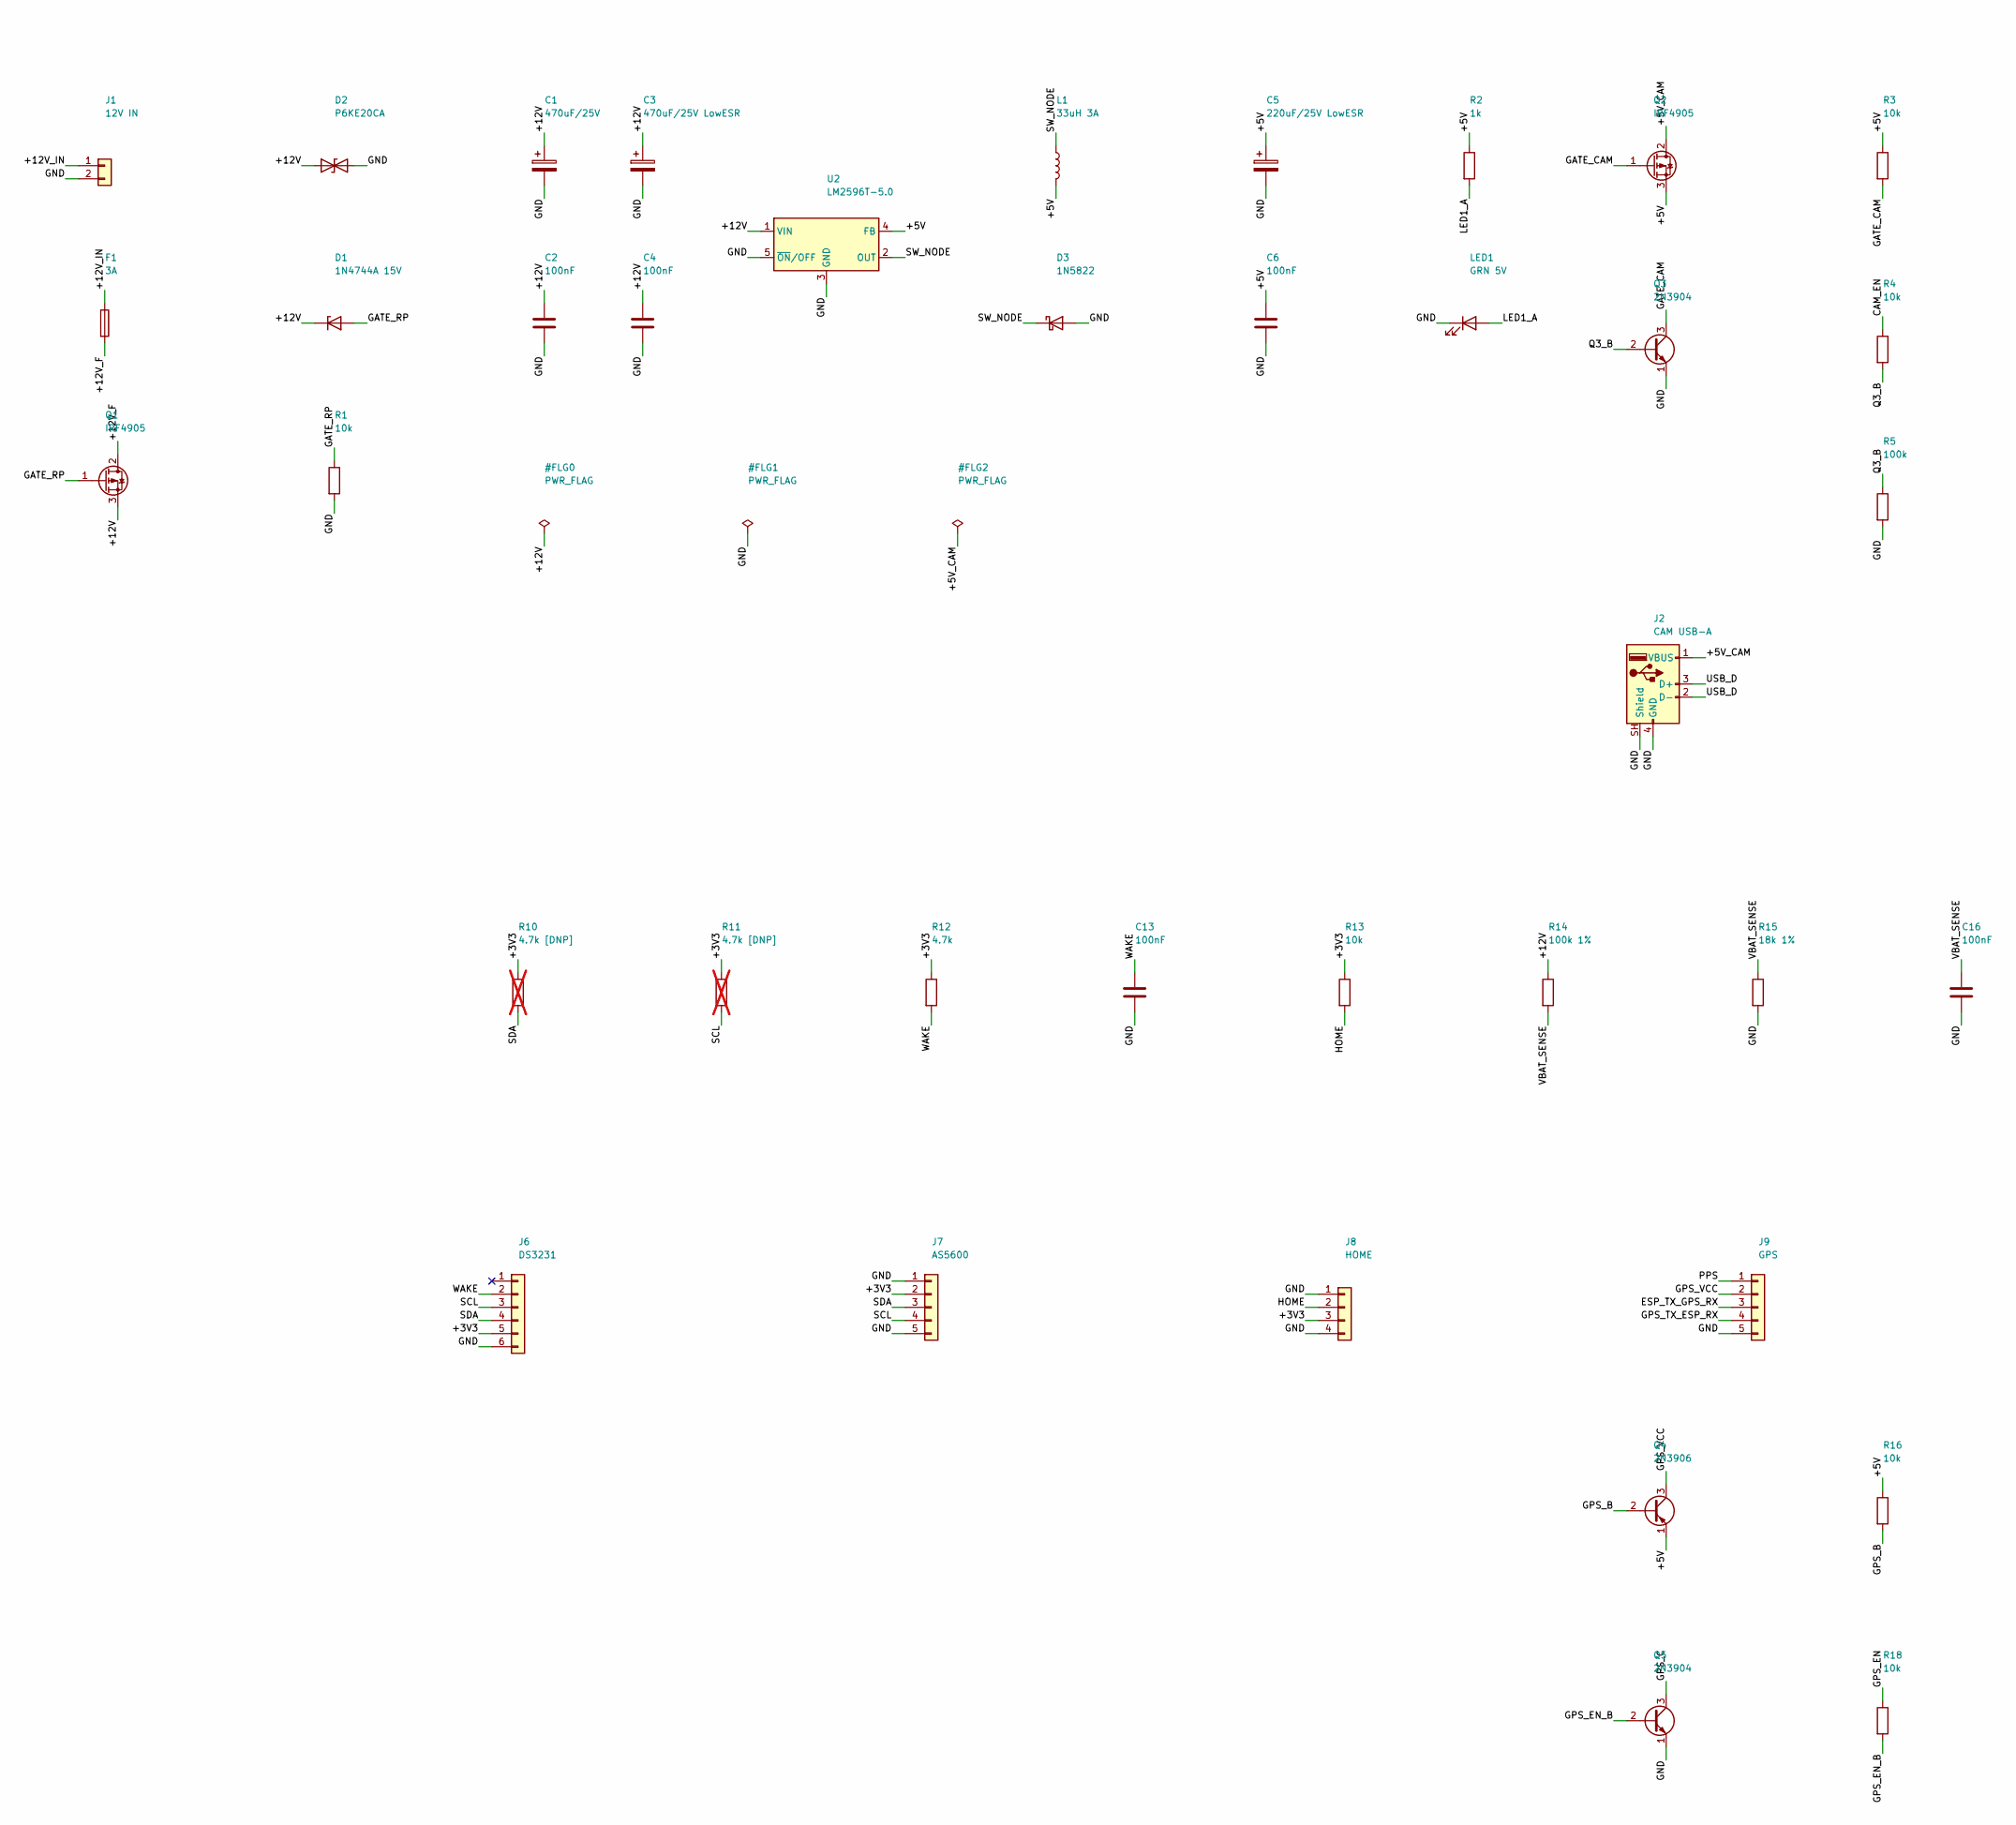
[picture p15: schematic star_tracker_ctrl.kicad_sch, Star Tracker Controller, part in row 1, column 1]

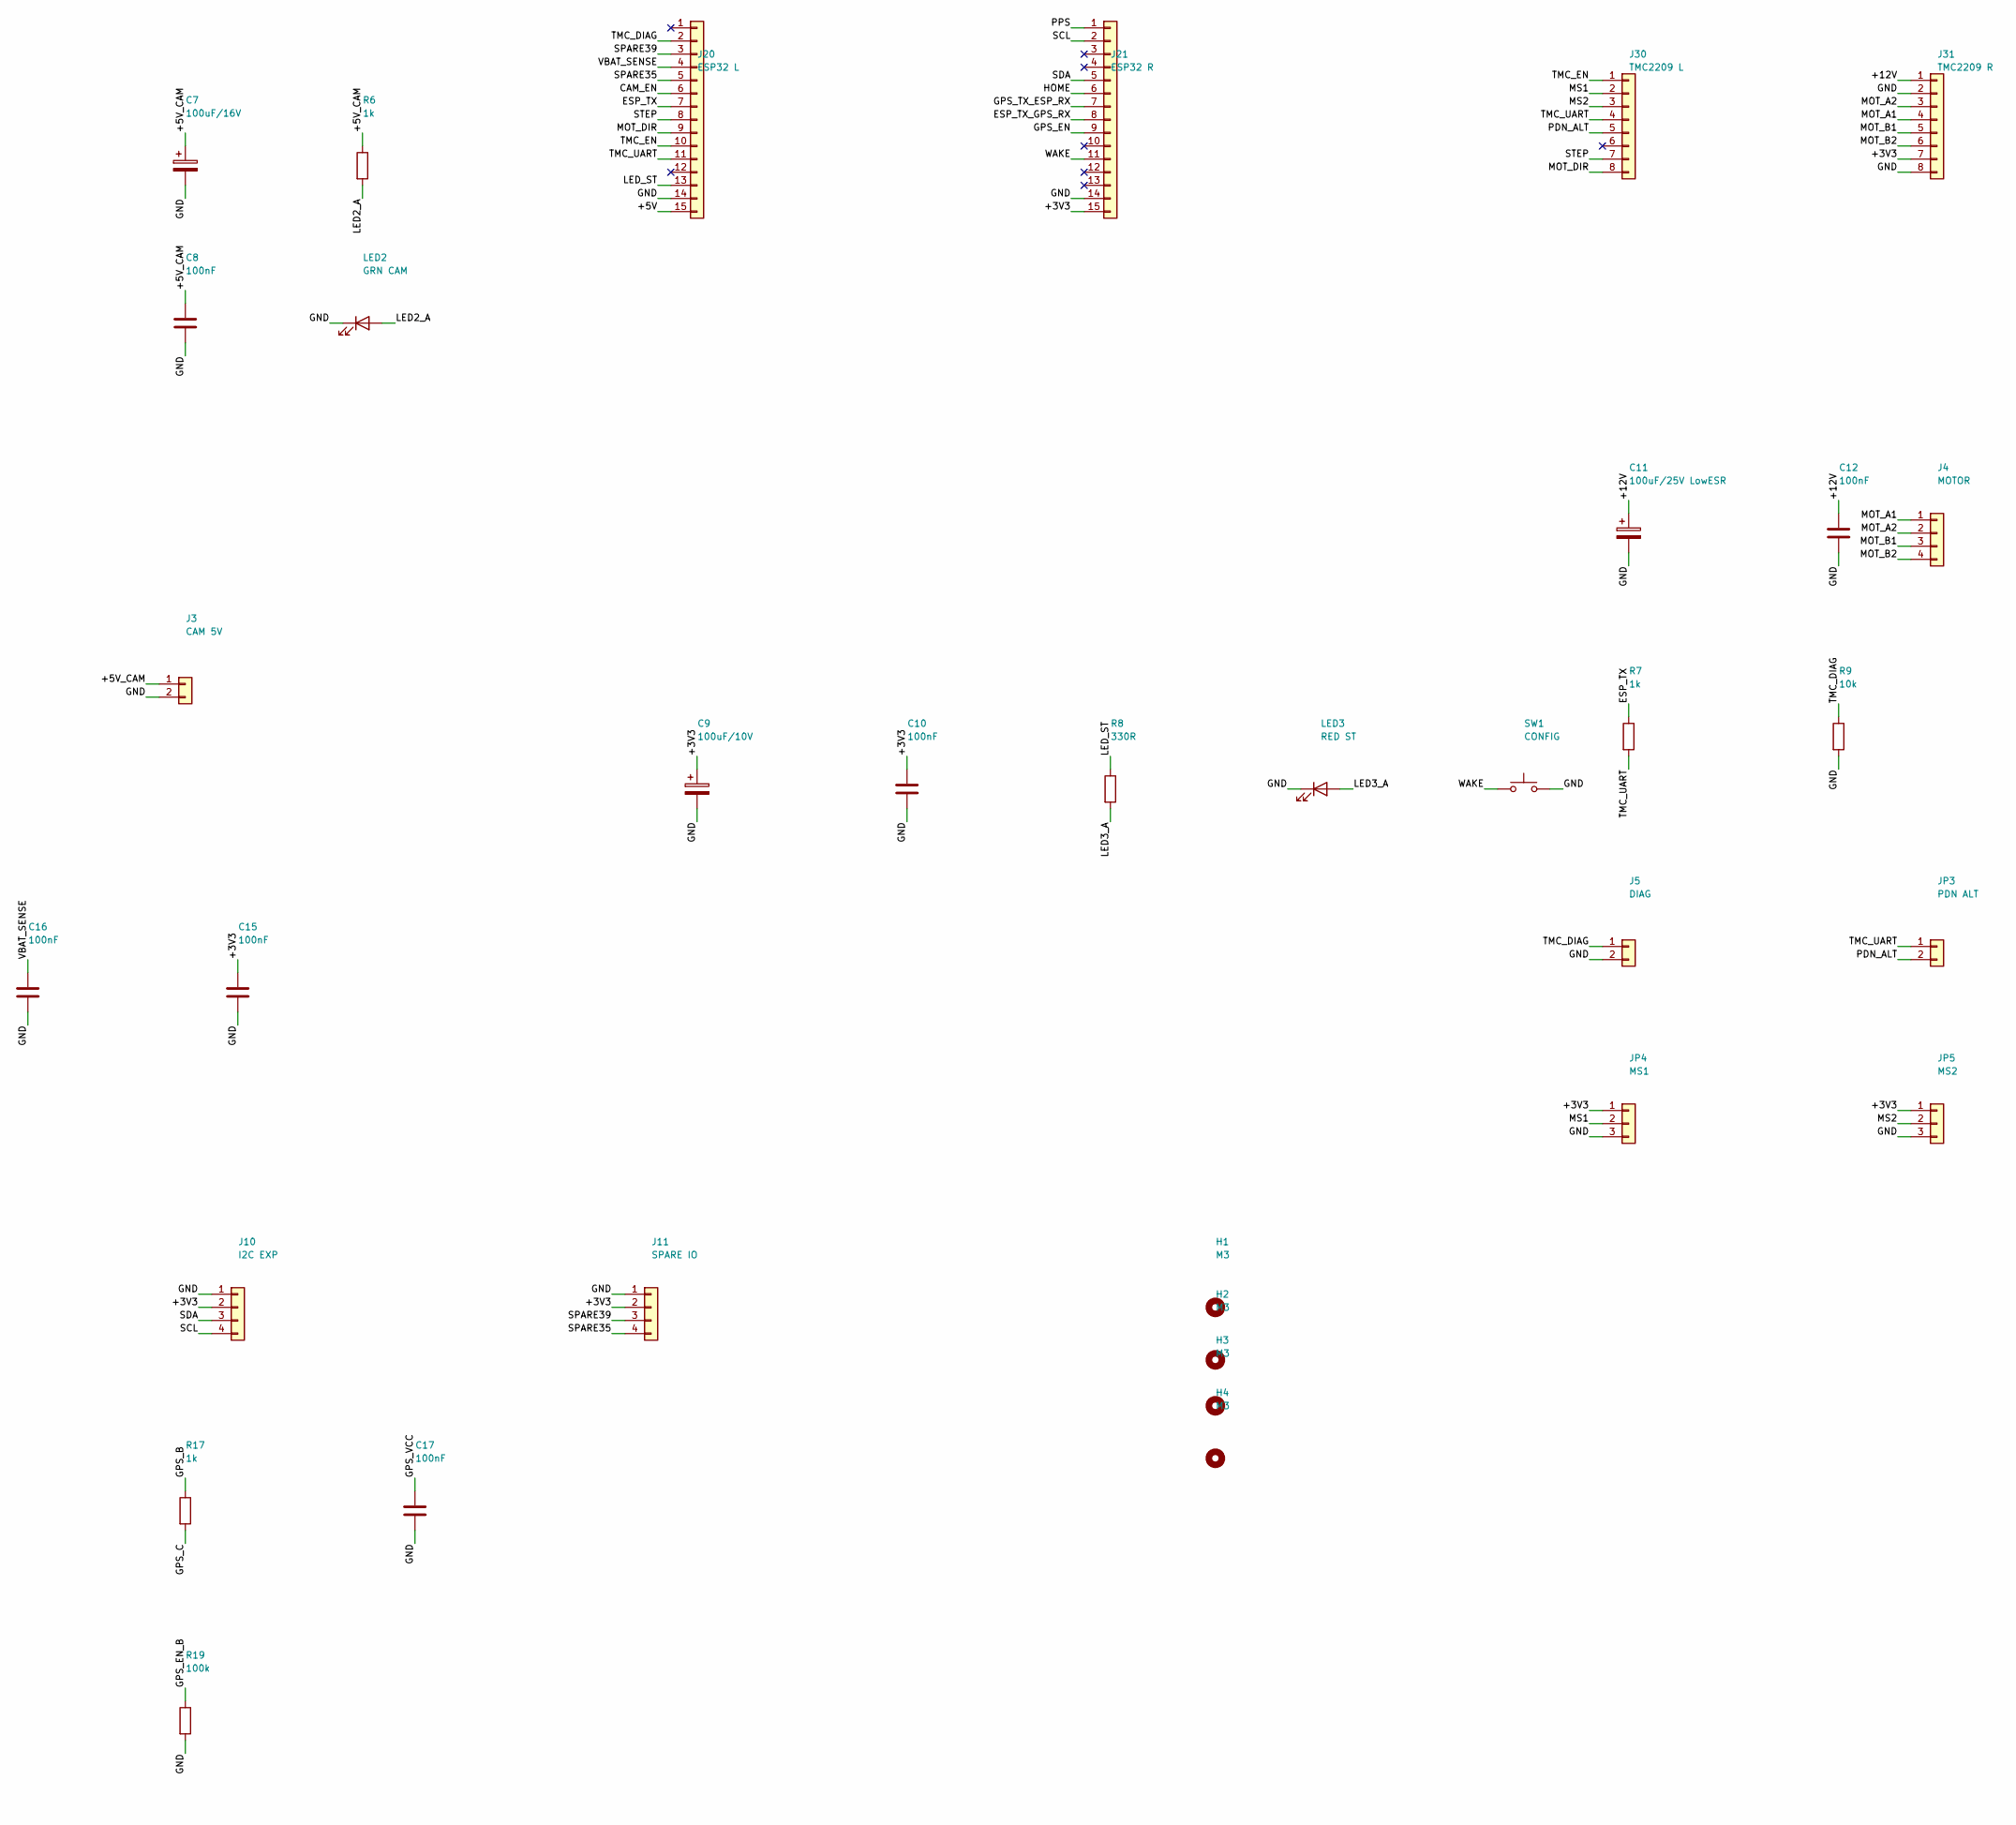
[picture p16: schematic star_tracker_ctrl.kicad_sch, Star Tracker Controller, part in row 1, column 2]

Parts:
C1: 470uF/25V; CP_Radial_D10.0mm_P5.00mm
C2, C4, C6, C8, C10, C12, C13, C15, C16, C17: 100nF; C_Disc_D5.0mm_W2.5mm_P2.50mm
C3: 470uF/25V LowESR; CP_Radial_D10.0mm_P5.00mm
C5: 220uF/25V LowESR; CP_Radial_D10.0mm_P5.00mm
C7: 100uF/16V; CP_Radial_D8.0mm_P3.50mm
C9: 100uF/10V; CP_Radial_D8.0mm_P3.50mm
C11: 100uF/25V LowESR; CP_Radial_D10.0mm_P5.00mm
D1: 1N4744A 15V; D_DO-41_SOD81_P2.54mm_Vertical_CathodeUp
D2: P6KE20CA; D_DO-15_P3.81mm_Vertical_AnodeUp
D3: 1N5822; D_DO-201AD_P5.08mm_Vertical_CathodeUp
F1: 3A; Fuseholder_Clip-5x20mm_Littelfuse_111_Inline_P20.00x5.00mm_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
H1, H2, H3, H4: M3; MountingHole_3.2mm_M3
J1: 12V IN; TerminalBlock_MaiXu_MX126-5.0-02P_1x02_P5.00mm
J2: CAM USB-A; USB_A_Wuerth_614004134726_Horizontal
J3: CAM 5V; TerminalBlock_MaiXu_MX126-5.0-02P_1x02_P5.00mm
J4: MOTOR; TerminalBlock_MaiXu_MX126-5.0-04P_1x04_P5.00mm
J5: DIAG; PinHeader_1x02_P2.54mm_Vertical
J6: DS3231; PinSocket_1x06_P2.54mm_Vertical
J7: AS5600; PinHeader_1x05_P2.54mm_Vertical
J8: HOME; PinHeader_1x04_P2.54mm_Vertical
J9: GPS; PinHeader_1x05_P2.54mm_Vertical
J10: I2C EXP; PinHeader_1x04_P2.54mm_Vertical
J11: SPARE IO; PinHeader_1x04_P2.54mm_Vertical
J20: ESP32 L; PinSocket_1x15_P2.54mm_Vertical
J21: ESP32 R; PinSocket_1x15_P2.54mm_Vertical
J30: TMC2209 L; PinSocket_1x08_P2.54mm_Vertical
J31: TMC2209 R; PinSocket_1x08_P2.54mm_Vertical
JP3: PDN ALT; PinHeader_1x02_P2.54mm_Vertical
JP4: MS1; PinHeader_1x03_P2.54mm_Vertical
JP5: MS2; PinHeader_1x03_P2.54mm_Vertical
L1: 33uH 3A; L_Radial_D12.0mm_P5.00mm_Fastron_11P
LED1: GRN 5V; LED_D3.0mm
LED2: GRN CAM; LED_D3.0mm
LED3: RED ST; LED_D3.0mm
Q1, Q2: IRF4905; TO-220-3_Vertical
Q3, Q5: 2N3904; TO-92_Inline_Wide
Q4: 2N3906; TO-92_Inline_Wide
R1, R3, R4, R9, R13, R16, R18: 10k; R_Axial_DIN0207_L6.3mm_D2.5mm_P2.54mm_Vertical
R2, R6, R7, R17: 1k; R_Axial_DIN0207_L6.3mm_D2.5mm_P2.54mm_Vertical
R5, R19: 100k; R_Axial_DIN0207_L6.3mm_D2.5mm_P2.54mm_Vertical
R8: 330R; R_Axial_DIN0207_L6.3mm_D2.5mm_P2.54mm_Vertical
R10, R11: 4.7k [DNP]; R_Axial_DIN0207_L6.3mm_D2.5mm_P2.54mm_Vertical; not fitted
R12: 4.7k; R_Axial_DIN0207_L6.3mm_D2.5mm_P2.54mm_Vertical
R14: 100k 1%; R_Axial_DIN0207_L6.3mm_D2.5mm_P2.54mm_Vertical
R15: 18k 1%; R_Axial_DIN0207_L6.3mm_D2.5mm_P2.54mm_Vertical
SW1: CONFIG; SW_PUSH_6mm
U2: LM2596T-5.0; TO-220-5_P3.4x3.7mm_StaggerOdd_Lead3.8mm_Vertical

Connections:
+3V3: C9.1, C10.1, C15.1, J6.5, J7.2, J8.3, J10.2, J11.2, J21.15, J31.7, JP4.1, JP5.1, R10.1, R11.1, R12.1, R13.1
+5V: C5.1, C6.1, J20.15, L1.2, Q2.3 (S), Q4.1 (E), R2.1, R3.1, R16.1, U2.4 (FB)
+5V_CAM: C7.1, C8.1, J2.1 (VBUS), J3.1, Q2.2 (D), R6.1
+12V: C1.1, C2.1, C3.1, C4.1, C11.1, C12.1, D1.1 (K), D2.1 (A1), J31.1, Q1.3 (S), R14.1, U2.1 (VIN)
+12V_F: F1.2, Q1.2 (D)
+12V_IN: F1.1, J1.1
CAM_EN: J20.6, R4.1
ESP_TX: J20.7, R7.1
ESP_TX_GPS_RX: J9.3, J21.8
GATE_CAM: Q2.1 (G), Q3.3 (C), R3.2
GATE_RP: D1.2 (A), Q1.1 (G), R1.1
GND: C1.2, C2.2, C3.2, C4.2, C5.2, C6.2, C7.2, C8.2, C9.2, C10.2, C11.2, C12.2, C13.2, C15.2, C16.2, C17.2, D2.2 (A2), D3.2 (A), J1.2, J2.4 (GND), J2.SH (Shield), J3.2, J5.2, J6.6, J7.1, J7.5, J8.1, J8.4, J9.5, J10.1, J11.1, J20.14, J21.14, J31.2, J31.8, JP4.3, JP5.3, LED1.1 (K), LED2.1 (K), LED3.1 (K), Q3.1 (E), Q5.1 (E), R1.2, R5.2, R9.2, R15.2, R19.2, SW1.2, U2.3 (GND), U2.5 (~ON/OFF)
GPS_B: Q4.2 (B), R16.2, R17.1
GPS_C: Q5.3 (C), R17.2
GPS_EN: J21.9, R18.1
GPS_EN_B: Q5.2 (B), R18.2, R19.1
GPS_TX_ESP_RX: J9.4, J21.7
GPS_VCC: C17.1, J9.2, Q4.3 (C)
HOME: J8.2, J21.6, R13.2
LED1_A: LED1.2 (A), R2.2
LED2_A: LED2.2 (A), R6.2
LED3_A: LED3.2 (A), R8.2
LED_ST: J20.13, R8.1
MOT_A1: J4.1, J31.4
MOT_A2: J4.2, J31.3
MOT_B1: J4.3, J31.5
MOT_B2: J4.4, J31.6
MOT_DIR: J20.9, J30.8
MS1: J30.2, JP4.2
MS2: J30.3, JP5.2
PDN_ALT: J30.5, JP3.2
PPS: J9.1, J21.1
Q3_B: Q3.2 (B), R4.2, R5.1
SCL: J6.3, J7.4, J10.4, J21.2, R11.2
SDA: J6.4, J7.3, J10.3, J21.5, R10.2
SPARE35: J11.4, J20.5
SPARE39: J11.3, J20.3
STEP: J20.8, J30.7
SW_NODE: D3.1 (K), L1.1, U2.2 (OUT)
TMC_DIAG: J5.1, J20.2, R9.1
TMC_EN: J20.10, J30.1
TMC_UART: J20.11, J30.4, JP3.1, R7.2
USB_D: J2.2 (D-), J2.3 (D+)
VBAT_SENSE: C16.1, J20.4, R14.2, R15.1
WAKE: C13.1, J6.2, J21.11, R12.2, SW1.1

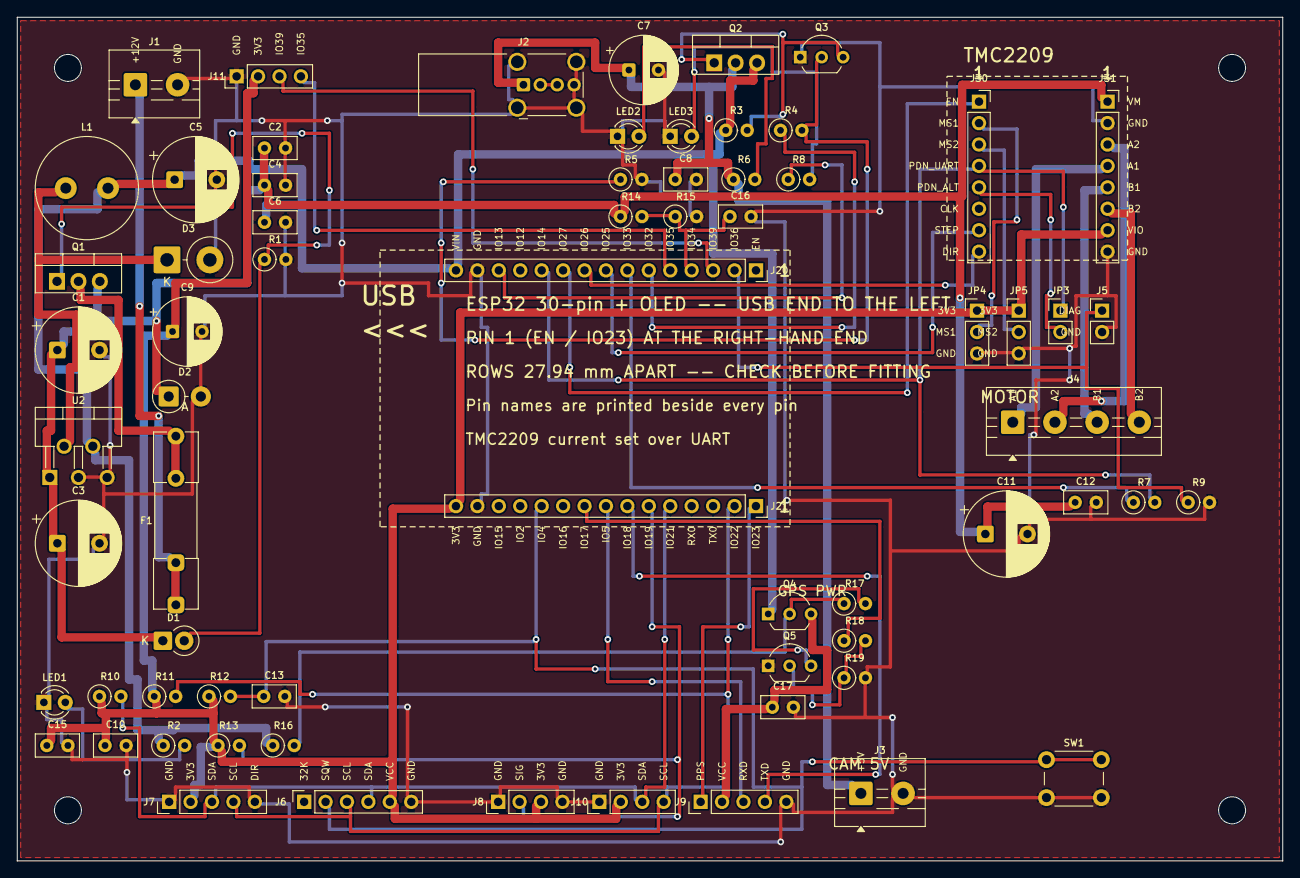
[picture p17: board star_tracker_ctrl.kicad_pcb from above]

Board: 2 copper layers, 150.0 x 100.0 mm, 72 parts (0 on the bottom side), 45 nets.

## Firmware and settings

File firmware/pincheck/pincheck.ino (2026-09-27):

// =====================================================================
//  pincheck.ino -- Slice 0, step 1.  Answers the one question the board
//  photo cannot: which GPIOs does the on-board OLED actually use?
//
//  Sources disagree for the ideaspark ESP32 + 0.96" OLED. One says the
//  panel is on GPIO 21/22 (the ESP32 I2C defaults), another says 4/15/16.
//  It decides whether WAKE can live on GPIO 4, so guess and you scrap a
//  board.
//
//  Flash it, open the serial monitor at 115200, read the verdict.
//  Nothing else need be connected -- no RTC, no encoder, no driver.
// =====================================================================

#include <Arduino.h>
#include <Wire.h>

// The two candidate buses, plus the third pin some boards use for RESET.
struct Bus { const char *name; int sda, scl; };
static const Bus BUSES[] = {
  { "GPIO21 (SDA) / GPIO22 (SCL)  <- ESP32 default", 21, 22 },
  { "GPIO4  (SDA) / GPIO15 (SCL)  <- Heltec style",   4, 15 },
  { "GPIO5  (SDA) / GPIO4  (SCL)",                    5,  4 },
};

static const char *whoIs(uint8_t a) {
  switch (a) {
    case 0x3C: case 0x3D: return "SSD1306 OLED";
    case 0x36:            return "AS5600 encoder";
    case 0x68:            return "DS3231 RTC";
    case 0x57:            return "DS3231 EEPROM (AT24C32)";
    case 0x0D: case 0x1E: return "magnetometer";
    default:              return "unknown";
  }
}

static int scan(const Bus &b) {
  Wire.end();
  if (!Wire.begin(b.sda, b.scl, 100000)) {
    Serial.printf("  %-44s  bus would not start\n", b.name);
    return 0;
  }
  delay(50);
  int found = 0;
  for (uint8_t a = 1; a < 127; a++) {
    Wire.beginTransmission(a);
    if (Wire.endTransmission() == 0) {
      if (!found) Serial.printf("  %s\n", b.name);
      Serial.printf("      0x%02X  %s\n", a, whoIs(a));
      found++;
    }
  }
  if (!found) Serial.printf("  %-44s  nothing\n", b.name);
  return found;
}

void setup() {
  Serial.begin(115200);
  delay(1500);
  Serial.println("\n\n=== star tracker :: pin check ===");
  Serial.printf("chip %s  rev %d  %d core(s)  flash %u MB\n",
                ESP.getChipModel(), ESP.getChipRevision(), ESP.getChipCores(),
                (unsigned)(ESP.getFlashChipSize() / (1024 * 1024)));
  Serial.printf("PSRAM: %s   <- must be NONE; WROVER's PSRAM sits on GPIO16/17\n",
                ESP.getPsramSize() ? "PRESENT (this is a WROVER!)" : "none");

  Serial.println("\nI2C scan:");
  int hits = 0;
  for (const Bus &b : BUSES) hits += scan(b);

  Serial.println("\n--- what this means -------------------------------");
  if (!hits) {
    Serial.println("No devices anywhere. If the OLED is lit, it is not I2C;");
    Serial.println("if it is dark, the panel may be SPI or on other pins.");
  }
  Serial.println("If 0x3C answered on 21/22  -> OLED shares the sensor bus.");
  Serial.println("   WAKE stays on GPIO4, nothing else changes.");
  Serial.println("If 0x3C answered on 4/15   -> those pins are spoken for.");
  Serial.println("   WAKE must move; report which bus answered.");
}

void loop() {
  delay(10000);
}

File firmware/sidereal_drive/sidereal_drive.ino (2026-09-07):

// =====================================================================
//  sidereal_drive.ino  --  ESP32 sidereal-rate stepper clock
//
//  The whole point: the step interval is 5843.377... us, which is NOT an
//  integer. Rounding it to 5843 us loses 0.377 us per step * 171 steps/s
//  = 65 us/s = 5.6 s per day = 23 arcsec of drift. Visible.
//
//  So we never round. We carry the remainder in a 64-bit accumulator,
//  Bresenham style, and the long-term rate is EXACT -- limited only by
//  the crystal (~20 ppm, i.e. ~0.3 arcsec/day. Irrelevant).
// =====================================================================

#include <Arduino.h>

// ---- pins (TMC2209 / A4988 / DRV8825 all work) ----------------------
const int PIN_STEP = 25;
const int PIN_DIR  = 26;
const int PIN_EN   = 27;   // active LOW on most carriers

// ---- the two numbers that define everything -------------------------
// Sidereal day = 86164.0905 s, in microseconds.
const uint64_t SIDEREAL_US = 86164090500ULL;

// Microsteps per revolution of the OUTPUT shaft.
// Pick ONE of these to match the final stage you actually built.

// (A) all-printed train: 8*8*8*9 = 4608:1, module 1.0 throughout
//     -> 5843.377 us, 171.13 steps/s, motor 3.209 rpm, 0.088 arcsec/ustep
// const uint64_t USTEPS_PER_REV = 200ULL * 16ULL * 4608ULL;  // 14,745,600

// (B) laser final stage: 8*8*8*4 = 2048:1, module 2.0 last stage
//     1/32 microstepping keeps the motor smooth at its lower speed
//     -> 6573.80 us, 152.13 steps/s, motor 1.426 rpm, 0.099 arcsec/ustep
const uint64_t USTEPS_PER_REV = 200ULL * 32ULL * 2048ULL;    // 13,107,200

// This is the ONLY line that changes between the two builds. That is the
// entire point of the accumulator below -- the ratio never has to be tidy.

uint64_t acc     = 0;   // remainder carry, units of 1/USTEPS_PER_REV us
int64_t  next_us = 0;

void setup() {
  Serial.begin(115200);
  pinMode(PIN_STEP, OUTPUT);
  pinMode(PIN_DIR,  OUTPUT);
  pinMode(PIN_EN,   OUTPUT);

  digitalWrite(PIN_DIR, HIGH);    // set for your hemisphere / gear parity
  digitalWrite(PIN_EN,  LOW);     // enable

  next_us = esp_timer_get_time(); // 64-bit monotonic us. Never wraps.
}

void loop() {
  if (esp_timer_get_time() >= next_us) {
    digitalWrite(PIN_STEP, HIGH);
    delayMicroseconds(3);           // most drivers need >1 us
    digitalWrite(PIN_STEP, LOW);

    // exact rational advance: dt alternates 5843 / 5844, mean 5843.377
    acc += SIDEREAL_US;
    uint64_t dt = acc / USTEPS_PER_REV;   // (A) 5843/5844   (B) 6573/6574
    acc -= dt * USTEPS_PER_REV;
    next_us += (int64_t)dt;
  }

  // Everything else -- StallGuard polling, encoder sanity check, buttons,
  // slew mode -- goes here. At 171 steps/s you have ~5.8 ms of slack per
  // step, which is an eternity.
}

// ---------------------------------------------------------------------
//  NOTES
//
//  * Run the motor at LOW current (300-400 mA). It needs almost no torque
//    through a 4608:1 train, and low current means less vibration and heat.
//
//  * TMC2209 in StealthChop at 1/16 or 1/32 is dramatically smoother than
//    an A4988. Worth the extra few dollars.
//
//  * Feedback: do NOT close a loop on speed -- the crystal is already
//    better than your mechanics by four orders of magnitude. Use
//    StallGuard (TMC2209, over UART) or an AS5600 on an intermediate
//    shaft purely to answer "is the train still turning?"
//
//  * Want a different gear ratio? Change only USTEPS_PER_REV. Any ratio
//    works -- that is the whole point of the accumulator.
//
//  * Obsessive tier: discipline next_us against a GPS PPS edge. But
//    polar-alignment error will still dominate by 1000x.
// ---------------------------------------------------------------------

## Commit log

2026-09-07 Initial commit: sidereal drive gearbox
    A 3D-printed 2048:1 gear train that turns a camera at one revolution per
    sidereal day, driven by a stepper on an ESP32.
    Design:
    - 8x8x8x4 = 2048:1. Stages 1-3 are module 1.0 (15T/120T); the final stage
    is module 2.0 (24T/96T) because short-exposure trailing scales as
    1/r_pinion, not with the wheel. That choice cuts the dominant error from
    ~60 to ~19 arcsec per 300 s sub.
    - Square fold, 226.5 x 279 mm footprint, 24.5 mm stack.
    - Firmware carries the non-integer step interval (6573.80 us) in a 64-bit
    accumulator, so the long-term rate is exact for any ratio.
    Contents:
    - star_tracker_gears.scad self-contained involute generator, no libraries.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
    [star_tracker_gears.scad]
2026-09-07 Add system architecture and BOM for scheduled operation
    Extends scope from a bare gearbox to a standalone device: wake at dusk,
    run a GoPro HERO6 night lapse until dawn, rewind for the next night.
    Decisions recorded in HARDWARE.md:
    - ESP32 over Pi Zero/Pi 4. The deciding factor is unattended robustness,
    not speed — an SD card half-written when the battery dies may not come
    back, LittleFS does. Also 0.6 W cheaper, which is ~7 Wh a night.
    - GoPro over WiFi gpControl, not BLE. The earlier HERO5 Bluetooth failure
    was expected: the documented GoPro BLE API starts at HERO9. HERO6 uses
    HTTP at 10.5.5.9 with a Wake-on-LAN magic packet to wake it.
    - Captive web UI on the ESP32's own AP rat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
2026-09-07 Add output shaft, AS5600 encoder mount, and bearing gauge
    Five new printed parts put an absolute encoder on the output shaft, so
    "home" is read at power-up rather than searched for.
    Mechanical approach:
    - The output becomes the one rotating shaft, in two 625ZZ 30 mm apart.
    The magnet must sit on the axis and turn with the wheel, and the camera
    load wants real bearings regardless.
    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
    [star_tracker_gears.scad]
2026-09-07 Make the baseplate a real part with a cutting SVG
    It had been a render placeholder: module baseplate(margin, t=4), drawn only
    in the assembly preview, with no build target and no stated thickness.
    Now parameterised, with a 2D profile that is the single source for both the
    STL and the cutting SVG:
    - bp_t thickness (4 mm 6061 recommended), plus hole sizes for every feature.
    - Outline is a hull of lobes at the five shaft centres rather than a slab
    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
    [star_tracker_gears.scad]
2026-09-07 Rewrite README as a resume document
    The README had drifted behind the work again. Rewritten so the project can
    be picked up cold.
    Adds:
    - A status table and an explicit "next three things", so resuming does not
    require re-reading the whole history.
    - The baseplate and the output-shaft/encoder assembly, neither of which
    existed when the README was last touched.
    - The measured printer calibration constants in one place, with how each
    was obtained. These are the hardest-won numbers in the project and were
    only recorded inside build.ps1.
    - A "traps worth remembering" section: the two OpenSCAD behaviours that
    silently produce wrong output, the two PowerShell 5.1 native-command
    gotcha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
2026-09-09 Split the bearing tower; fix blind flange bolt holes
    The one-piece tower does not print, and not because of one overhang -- it
    fails in both orientations for different reasons:
    - bottom-up, the first layer is a 2.75 mm ring, only 166 mm2 of bed contact
    under a 35 mm tall part
    - top-down, the flange top face becomes an 8 mm wide 90 degree ledge
    Split at the taper/flange junction (z=0, where the taper meets the max
    radius). Both halves now print flange-face-down on ~1080 mm2, 6.5x the bed
    contact, and neither has an overhang: the lower half's cone shrinks going
    up, the upper steps inward going up.
    Alignment is three separate dowels, not an integral male pin. Both mating
    faces want to be on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
    [star_tracker_gears.scad]
2026-09-17 Add a real DXF for the baseplate; widen the tower bolt circle
    SendCutSend wants DXF, and OpenSCAD's DXF writer is not usable for it: for
    this part it emits 708 loose LINE segments, every hole a faceted polygon,
    not a single CIRCLE entity.
    make_baseplate_dxf.py writes R12 with exact geometry instead. The outline
    is the convex hull of the lobes, which decomposes exactly into circular
    arcs joined by their common external tangents -- 4 ARC + 4 LINE -- and the
    16 holes are true CIRCLE entities. 24 entities against 708.
    baseplate_geom.py is new and is now the single source for the DXF, the SVG
    and the 1:1 PDF, so the three cannot drift apart.
    The generator self-verifies and that caught a real m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
    [baseplate_cut.dxf, star_tracker_gears.scad]
2026-09-17 Baseplate 4.3 mm as ordered; PDF now uses the shared geometry
    SendCutSend's nearest stock to the designed 4.0 mm was 4.3. Checked rather
    than assumed, and it is dimensionally free: every gear height is referenced
    from the plate's TOP face, so thickness lives entirely below the datum.
    Nothing above the plate moves. It buys 24% more bending stiffness (t^3) for
    13 g.
    Two real consequences, both fasteners: tower flange grip becomes 8.3 mm, and
    the motor bolts want M3x10 rather than M3x8 into the NEMA17's ~4.5 mm tapped
    holes.
    The cut files are 2D, so the DXF already sent is unaffected and does not
    need resubmitting.
    Also fixes something I claimed last commit but had not actually done:
    make_ba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
    [star_tracker_gears.scad]
2026-09-17 Add a baseplate assembly guide
    A bench reference rather than a template: plate outline and holes solid,
    everything that sits above it dashed (gear tip circles, NEMA17 body), five
    numbered stations plus the wedge interface, and a table giving spacer
    height, what stacks on each shaft bottom-to-top, and fastener sizes.
    Deliberately not to scale and labelled so in red at the top. The gear
    footprint is 226 x 279 mm and will not fit Letter at 1:1; drilling stays
    with baseplate_template.pdf.
    Surfaces things that were only implicit before -- most usefully that only
    THREE of the five printed spacers actually get used. S0's would fall
    through the dia 23 motor bore, and S4's job is done by the bearin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
2026-09-27 Add the 24 h dial target and fix -Only on the python-built docs
    Pre-existing work in the tree, committed as its own change so it does not
    get tangled with the controller board.
    - build.ps1 gains $OutBore (the output wheel bore now references the 22 mm
    register by name rather than a literal) and a docs target for the dial
    - make_dial_pdf.py draws out/docs/final_wheel_24h_dial.pdf
    - the PDF/DXF docs are built by python, not OpenSCAD, so they are not in
    $targets; -Only on one of them used to throw "No targets matched"
    - refreshed renders and baseplate PDFs from the same build run
2026-09-27 Firmware architecture, and a through-hole controller PCB
    FIRMWARE.md is the resumable plan: the position-servo step engine, the
    state machine, the schedule format and validation, and the build order.
    Two decisions worth naming -- tracking is the mission and the camera is
    best-effort (so bench repeatability runs work with no camera at all), and
    the step generator servos to a computed position rather than firing on a
    deadline, which makes it immune to WiFi stalls and gives free mid-night
    resume.
    hardware/ is a 127 x 84 mm two-layer controller board, generated from
    Python rather than drawn by hand:
    design.py netlist, values, the ESP32 and TMC2209 pin maps
    place.py floorplan; layout.p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
    [BOM.csv, star_tracker_ctrl.kicad_pcb, star_tracker_ctrl.kicad_sch]
2026-09-27 Drop the stale root copy of baseplate_assembly_guide.pdf
    make_baseplate_guide.py writes out/docs/baseplate_assembly_guide.pdf, which
    is what README and PRINTING.md point at. The root copy was a leftover from
    an older run -- same size, different content, referenced by nothing.
2026-09-27 Drop the stale root copies of baseplate_cut.svg and baseplate_template.pdf
    Same leftovers as the assembly guide: make_baseplate_pdf.py and
    make_baseplate_dxf.py write into out/docs/, which is where README and
    PRINTING.md send you. The root copies were from an older run and had
    drifted from the generated ones -- a real trap on files whose whole job
    is to be sent to a fab or drilled against.
    The repo root now holds only sources: the .scad, the generators and the
    docs.
2026-09-27 Rev B: fix a mirrored ESP32 socket, add GPS, grow the board to 150x100
    The important one first. The ESP32 socket in rev A was MIRRORED. The module's
    left column was on the top row with pin 1 at the left, and that combination is
    neither of the two legal placements -- the transform from module coordinates
    to board coordinates had determinant -1, so the module would have had to be
    flipped over to fit. Every pin was on the wrong signal. Fabricated, it would
    have been scrap with no obvious cause.
    A DevKitC laid on its side has exactly two legal orientations:
    90 CW : left column = TOP row, pin 1 at the RIGHT, USB at the LEFT
    90 CCW: left column = BOTTOM row, pin 1 at the LEFT, USB at the RIG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
    [BOM.csv, star_tracker_ctrl.kicad_pcb, star_tracker_ctrl.kicad_sch]
2026-09-27 Block the PCB generator until the 30-pin module's map is known; add RESUME.md
    The module in hand is a 30-pin ideaspark ESP32 + 0.96" OLED, not the 38-pin
    DevKitC the board is drawn for. Rather than let that sit as a comment, the
    generator now refuses to run:
    ESP32_LEFT has 19 entries but ESP32_PINS_PER_SIDE is 15. The pin map has
    not been updated for this module -- fill it in from the board's silkscreen
    before generating.
    Pin count and row spacing now flow from single constants through both the
    netlist and the floorplan, with a cross-check between the two modules and a
    guard that no signal lands on two ESP32 pins. After the mirrored-socket bug,
    the toolchain should stop rather than q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
    [design.py, gen_board.py, pincheck.ino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]
2026-09-27 Mechanical Rev B, Fritzing wiring project, and the assembly guide
    Mechanical Rev B -- eight conflicts found by drawing the assembly guide:
    - tower halves now clamp the baseplate (Rev A's cone sat inside it)
    - output shaft cut to 55 mm, clear of the 1/4-20 camera nut
    - motor screws M3x8 flat head; countersink the holes under the S1 wheel
    - printed hub washer on the bearing inner race; hub 1 mm shorter
    - AS5600 bracket stops on the tower's clamp disc
    - grub holes removed from gears that turn on fixed nails
    - upper hub 10 mm with a full-depth 1/4-20 nut pocket; M3x20 clamp
    hardware/fritzing: gen_fritzing.py writes star_tracker_wiring.fzz. Every
    part is a custom part carried in the file; the co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
    [star_tracker_gears.scad, star_tracker_wiring.fzz]
2026-09-28 Name GPS UART nets by direction; guide PDF and print styles
    design.py: the GPS UART nets were GPS_TX / GPS_RX, and as wired the
    ESP32's transmit (GPIO 5) reached the module's TXD -- TX to TX. They are
    now ESP_TX_GPS_RX (GPIO 5 to J9.3, module RXD) and GPS_TX_ESP_RX (J9.4,
    module TXD, to GPIO 18). GPIO 5 stays a transmit pin, so its boot strap
    is unaffected. The committed KiCad files keep the old nets until the
    30-pin redraw. FIRMWARE.md and RESUME.md follow.
    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
2026-09-28 Controller board Rev C for the 30-pin ideaspark ESP32
    Pin check (firmware/pincheck, 2026-09-27): ESP32-D0WD-V3, 4 MB, no PSRAM;
    the on-board OLED answers at 0x3C on GPIO 21/22, so it shares the sensor
    bus and GPIO 4 stays free for WAKE.
    design.py: the 30-pin map (15 per side, rows 27.94 mm). Upper row serves
    the driver, camera switch, divider and status LED; lower row the bottom
    connector strip. Changes from Rev B: TMC UART 33/14, DIAG 36, LED_ST 13,
    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
    [BOM.csv, star_tracker_ctrl.kicad_pcb, star_tracker_ctrl.kicad_sch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]
2026-10-01 Freeze Rev C PCB, add Mouser order CSVs and 1:1 fit template PDF
    Gerbers sent to fab; RESUME/CLAUDE.md note the freeze. Mouser CSVs for
    passives, semiconductors and backorder replacements (C5/C11 -> UHE1E221MPD).
    [mouser_backorder_replacements.csv, mouser_passives.csv, mouser_semiconductors.csv]
2026-10-01 RESUME: C5/C11 bought on Amazon (Innfeeltech 220uF/25V); Mouser replacement not ordered
2026-10-17 RESUME: Rev D layout notes 1-10 from building Rev C; baseplate ray5 template; Mouser reorder CSV
    Rev D notes: lateral fuse clips, TMCX spacing at J4, J2/J3 "power only"
    labels, SW1 CONFIG/WAKE, heatsink keep-outs for Q1/Q2/U2, jumper table,
    bottom-edge connector labels, transistor part numbers, Q4/GPS PWR overlap.
    Rev C board files unchanged.
2026-10-17 Assembly guide: beginner board section, probe maps, square-routed wiring
    Section B rewritten for a first-time solderer: one part kind at a time
    (resistors, ceramics, electrolytics, diodes/LEDs, male headers, female
    sockets, terminals, transistors, power parts), each with a "how" sheet and
    a top-down board map highlighting every spot with its value and a tick box;
    soldering basics, male vs female, a quick first-light check. Steps now
    numbered 1-70 straight through.
    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
2026-10-18 Assembly guide builds without the flatpack-guide kit installed
    Vendor the kit files the build needs: figs_beginner.js (board maps, probe
    bubbles, supply, colour bands, soldering figures) and kit/kicad_board.py +
    kit/kicad_nets.py (layout and schematic readers). build.py prefers these
    copies and falls back to ~/.claude/skills/flatpack-guide only if missing.
    Verified: a build with the kit path pointed at nothing gives identical
    output. kit/README.txt records the source and how to refresh.
2026-10-20 Loosen the wheel register and AS5600 sleeve; FreeCAD assembly model; Rev D notes 11-12
    Fits: the output wheel's Ø22 bore went onto a Ø22 hub register, zero
    clearance on paper; both printed 21.9 and would not go together. build.ps1
    gains $RegFit = 0.50 (the printer's post-under-hole rule) and builds the
    lower hub's register at 21.5; the wheel stays Ø22, no reprint. The AS5600
    bracket sleeve over the Ø22 tower tube goes from +0.3 to +0.5 (new
    os_bkt_fit). Reprint output_hub_lower.stl and as5600_bracket.stl.
    FreeCAD: cad/freecad/ has the gear assembly as star_tracker_gears.FCStd
    (25 parts, grouped and coloured, from the .scad via export_parts.py and
    build_freecad.py). The 58 MB STEP is git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
2026-10-24 AS5600 check firmware; shafts 1-3 move to #12 screws; bracket washer
    - firmware/as5600_check: read-only gap (AGC, MAGNITUDE, MD/ML/MH) and
    zero (raw vs 1024, seam check) readout on OLED + serial for guide
    steps 58/59, now marked "today". Flashed and run on the bare ESP32.
    - Nails did not work out: $Bore 5.20 -> 6.00 for #12 screws (5.49 mm);
    bp_shaft_d 4.9 -> 5.5 as drilled, nut under the plate. Docs and
    RESUME note updated; guide steps 2-3 still describe nails.
    - bracket_washer module + 1.5 mm x 21.5 disc target.
    - Guide magnet notes (steps 16, 18, 58); FreeCAD model and
    export_parts.py take build.ps1's overrides.
2026-10-25 Controller box, bench stand, Cura slicing, dial arcs, GoPro adapter
    - Controller box for the Rev C board: glued/screwed to the motor tube
    through gusseted ears, tab opening lined up with the tube notch.
    28 mm above the board (tallest part measured 25.4). Snap-in board
    standoffs. Lid with flush M3 caps (side screws into leaves at the
    under-plate corners), sealed top: no vents, OLED viewport with a
    recess for a glued clear panel, recessed contact label. GPS antenna
    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
